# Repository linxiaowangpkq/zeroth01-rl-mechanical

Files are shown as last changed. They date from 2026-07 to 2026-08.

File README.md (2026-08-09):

# Zeroth-01 v5 original 16-DoF physical/RL baseline

v5 restores the released Zeroth-01 16-joint topology and proportions. It adds no ankle-roll motors, shortened shins, claws or large palms. The bounded changes are a rounded head enlarged by 5 mm on every side, a removable M5Stack UnitV2 camera/microphone, a direct no-neck head mount, two compact fixed wrist supports, two 9 mm white lower-wider replaceable soles, and explicit FEETECH STS3250 housing/output interfaces.

## Clone with CAD payloads

The STEP/GLB binaries are stored with Git LFS. A GitHub branch ZIP contains only
small LFS pointer text files and is **not** a complete offline CAD/RL delivery.
Use a Git clone and materialize the payloads before running any checksum gate:

```bash
git lfs install
git clone --branch codex/zeroth01-v5-16dof-solidworks-motion https://github.com/linxiaowangpkq/zeroth01-rl-mechanical.git
cd zeroth01-rl-mechanical
git lfs pull
python cad/physical_mount_v5_original_16dof_solidworks_motion/verify_v5_delivery_manifest.py
```

The verifier reports `git_lfs_pointer_not_materialized` with this remediation
when a required binary has not been downloaded.

## Authoritative RL files

- URDF: `generated/urdf/physical_mount_v5_original_16dof_solidworks_motion/zeroth01_physical_mount_v5_original_16dof_solidworks_motion.urdf`
- MJCF/MJX: `generated/mujoco/physical_mount_v5_original_16dof_solidworks_motion/zeroth01_physical_mount_v5_original_16dof_solidworks_motion_mjx.xml`
- RL model contract: `cad/physical_mount_v5_original_16dof_solidworks_motion/RL_MODEL_CONTRACT.md`
- Actuator layout: `generated/config/physical_mount_v5_original_16dof_solidworks_motion_actuator_layout.json`
- Hardware calibration template: `generated/config/physical_mount_v5_original_16dof_solidworks_motion_hardware_calibration.csv`
- RL handoff: `generated/config/physical_mount_v5_original_16dof_solidworks_motion_rl_handoff.json`
- SHA-256 delivery ledger: `generated/config/physical_mount_v5_original_16dof_solidworks_motion_delivery_manifest.json`
- Release truth boundary: `reports/v5_original_16dof_solidworks_motion/release_gate.json`
- 85-component CAD manifest: `generated/cad/physical_mount_v5_original_16dof_solidworks_motion/ZEROTH01_V5_ORIGINAL_16DOF_SOLIDWORKS_MOTION_ASSEMBLY_MANIFEST.json`
- 85-component coloured neutral review GLB: `generated/cad/physical_mount_v5_original_16dof_solidworks_motion/ZEROTH01_V5_ORIGINAL_16DOF_NEUTRAL_REVIEW.glb`
- 17 rigid-link STEP files: `generated/cad/physical_mount_v5_original_16dof_solidworks_motion/motion_link_parts/`

Current digital evidence: 16 revolute joints and 16 purchased-exact STS3250 STEP occurrences; 85 components; 17 positive-volume valid B-Rep motion links; zero positive interference among all 3,570 neutral-pose component pairs; 490.489 mm CAD envelope height; 416.448 mm MJCF standing kinematic height; 2.745759 kg nominal URDF/MJCF mass; and MuJoCo 3.3.7 compile at `nq=23`, `nv=22`, `nu=16`. For locomotion, reset from `gait_neutral`; `official_standing` is retained as the released calibration/standing-checkpoint pose.

The hip-yaw case path is physical CAD rather than a floating marker: two integrated torso ribs/bosses per side accept two M2x8 rear-case screws, while a PCD14 four-hole bridge and four M3 sleeves drive the U-hip. The mount and screw stack is clear of each moving U-hip over its unchanged full joint limit.

Native SOLIDWORKS static rebuild and 32 isolated lower/upper-limit Motion runs for the current manifest remain **HOLD** because the existing SOLIDWORKS process is unresponsive. Old native gate files are stale and are not acceptance evidence; no Motion GIF is claimed until the current assembly produces real frames.

This is a digital RL release, not a physical manufacturing sign-off. Purchased-part fit, printed strength, screw/tool access, exact internal electronics, harness flex, bus IDs/zeros/directions, as-built link mass/COM/inertia, current, thermal behavior and policy traces require first-article measurement and SysID.

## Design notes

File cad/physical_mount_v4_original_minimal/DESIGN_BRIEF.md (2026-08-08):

# Zeroth-01 v4 connected design brief

## Frozen baseline

- Preserve the released Zeroth-01 load-bearing torso, shoulder/hip spacing, upper limbs, thighs, source feet and all neutral joint axes.
- ToddlerBot, KHR-3HV, TonyPi and Open Duck Mini inform serviceability, double support, cable routing and MJX/SysID workflow only; their geometry is not substituted.
- The v3 RL frame/axis corrections remain frozen.

## Released changes

1. Two-piece rounded head, nominally +5 mm left/right/top/bottom, source depth retained, hidden 0.8 mm shoulder clearances, no visible neck.
2. Removable M5Stack UnitV2 camera/microphone cradle and direct four-M3 torso nut plate.
3. Original lightweight wrist termination only: no square palm, claw, gripper, ball hand or heavy Q-hand.
4. No external rear service pod or backplate. Compute, battery and IMU packaging must be frozen inside the torso after exact components are selected.
5. No added black sole; source feet define the contact surface.
6. Eighteen purchased-exact STS3250 occurrences. Every output has a 2.05 mm PCD14 bridge; required child-side standoffs close the torque path.
7. Hip-yaw servos move 4 mm only along their unchanged axes to clear the source torso. Four M2 case screws and four M3 PCD14 output tie rods close each joint; no fictitious solid spacer is installed.
8. Mirrored direct-drive ankle-roll carriers retain the original foot path; lower-leg straight spans are shortened 18 mm without altering terminal interfaces.

## Blocking gates

- 18/18 exact actuators and complete case/output torque paths.
- Bilateral axis/placement symmetry.
- 75/75 native SolidWorks occurrences and portable dependencies.
- Zero unapproved B-Rep cross-component interference. Threaded fastener engagement is allowed only for the explicitly paired PCD14 M3 shanks and only below 1.25 mm³ per detected engagement.
- Height ≤500 mm; nominal mass ≤3 kg.
- URDF/MJCF compile and 64-pose primitive collision sweep passes.
- Physical walking/running remains HOLD until first-article fit, printed strength, internal electronics/harness packaging, measured mass/SysID, current, thermal and policy traces are complete.

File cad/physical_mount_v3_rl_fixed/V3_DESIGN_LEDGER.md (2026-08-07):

# Zeroth-01 Physical Mount v3.1 Compact RL-Fixed Design Ledger

## Robot metadata

- Robot: `zeroth01_physical_mount_v3_rl_fixed_18dof`.
- Baseline: released v2-minimal appearance and source-carrier geometry.
- Consumers: MuJoCo/MJX RL, URDF viewers, SolidWorks/CAD review, first-article print review.
- Units: URDF/MJCF use m, kg, s, rad; CAD uses mm.
- Body convention: right-handed, `+X` forward, `+Y` left, `+Z` up.
- Mesh source: v2-minimal STL files are millimetre meshes and therefore use URDF scale `0.001`.

## Why v3 is 18DoF

The v2 topology has shoulder-yaw, shoulder-pitch and elbow-yaw on each arm,
plus hip-yaw, hip-roll, hip-pitch, knee-pitch and ankle-pitch on each leg.
It cannot independently regulate sole roll and torso roll in single support.
v3 adds one ankle-roll joint and STS3250 package per side.  Retaining 16DoF
would leave BUG-009 unresolved and therefore cannot be called an all-issues fix.

## Kinematic frames and positive motion

All movable child frames are located on their physical shaft centre and are
world-axis aligned in the neutral pose.  This removes the old mesh-frame RPY
coupling that mislabeled hip yaw/roll axes.  Visual transforms preserve the
v2 neutral appearance; collision and inertial frames are authored independently.

| Joint family | Left neutral axis | Right neutral axis | Positive motion |
|---|---:|---:|---|
| shoulder yaw | `+Z` | `-Z` | arm moves forward under mirrored controls |
| shoulder pitch | `+Y` | `+Y` | arm pitches forward |
| elbow yaw (historical name) | `+X` | `-X` | forearm hinges under mirrored controls |
| hip yaw | `+Z` | `-Z` | toe direction yaws outward under mirrored controls |
| hip roll | `+X` | `-X` | pelvis shifts toward the named support side |
| hip pitch | `+Y` | `+Y` | thigh moves forward (`+X`) |
| knee pitch | `+Y` | `+Y` | knee flexes backward |
| ankle pitch | `+Y` | `+Y` | toe pitches upward |
| ankle roll | `+X` | `-X` | sole medial edge rises under mirrored controls |

Left/right joint anchors are generated from one averaged source datum and an
explicit reflection across `Y=0`.  The release tolerance is 0.25 mm, tighter
than the failed v2 0.75 mm gate.

## Standing envelope, mass and inertia ledger

- Pre-compaction v3 nominal mass: `3.095471828 kg`.
- v3.1 nominal RL mass target: exactly `2.969171828 kg`, below the hard
  `3.000 kg` ceiling by `30.828 g` before as-built identification.
- Native SolidWorks standing-height hard gate: `<=500.0 mm`.  The previous
  STEP measured `572.678 mm`; the compact model sinks the head into the upper
  torso, re-clocks only the two new ankle-roll servos so their 45.22 mm case
  axis is horizontal, and uses a verified `30 mm` ankle-roll centre spacing.
- Final native SolidWorks occurrence-box height is `499.236652 mm` (`PASS`);
  the independent diagnostic STEP height is `494.818 mm`.  The SolidWorks
  value is the conservative release gate, while the built robot must still be
  measured because the remaining nominal margin is only `0.763 mm`.
- STS3250-C001 model mass: `0.0745 kg` each, 18 units, total `1.341 kg`.
- Remaining nominal mass covers source carriers, fasteners, lightened v2
  appearance parts, battery, compute, the purchased interaction head and IMUs.
- The former K151 head and large plate are deleted.  Their replacement is one
  purchasable M5Stack CoreS3 K128 main unit at the official
  `54.0 x 54.0 x 15.5 mm` envelope.  The official `72.7 g` whole-set weight is
  conservatively assigned to the main unit even though the DinBase is omitted,
  plus a `6 g` allowance for the hidden 2 mm 6061 U-cradle.
- Actuator mass is owned exactly once: each of the 18 actuated child links owns
  one 74.5 g STS3250 contribution, so no link is lighter than its contained servo.
- Every link inertia is calculated from its primitive collision envelope and
  nominal link mass.  Confidence is `estimated_from_envelope`, not measured.
- `MASS_IDENTIFIED_PASS` remains false until the assembled links are weighed
  and their centres of mass are measured.  RL may use the nominal model with
  the published randomisation range, but it must not be called as-built truth.

## Collision ledger

- RL collision geometry is primitive-only: boxes, spheres, cylinders and capsules.
- Limb capsules are generated from the true joint-to-child vector rather than a
  hard-coded vertical box, so collision geometry follows the actual kinematic chain.
- The torso collision proxy is the central structural spine and deliberately
  excludes the shoulder cut-outs used by the two shoulder chains.
- Each sole has its own symmetric box collision and four contact frames.
- Detailed v2 visual meshes never participate in MJX contact.
- The printable 7 mm sole is lightened with a 2 mm skin and 5 mm perimeter/rib
  stack; its collision envelope remains a closed 7 mm box.

## STS3250 interface ledger

- Controlled dimensions: case `45.22 x 24.72 x 35.0 mm`, shaft centre 12.5 mm
  from the short end, 25T/5.9 mm output, M3x6 retention.
- Drawing-derived case holes: 4-M2.0, centres `X={-28.50, 8.30} mm`,
  `Y={-10.25, 10.25} mm` in the controlled shaft frame.
- The step.parts record `feetech_sts3250` is checksum-verified but its embedded
  STEP product is `ST-3235M-20211119-A_ASM`; it remains quarantined and is not
  treated as an exact C001 installation B-Rep.
- v3 uses the dimension-controlled STEP and the existing source carrier
  datums.  Full-print release remains blocked until one purchased STS3250
  passes the 4-M2/25T/rear-support first-article gauge.

## Full assembly ownership

- The native/full CAD handoff is driven by the external-part assembly manifest,
  not by a fused display solid.  It contains 51 independently addressable
  components: retained v2 carriers and white shells, 18 blue STS3250 instances,
  two ankle-roll carrier/horn sets, two 7 mm soles, CoreS3 and its hidden cradle.
- Servo instance IDs `S01`--`S18`, shaft frames and source part paths are recorded
  in the manifest and actuator-layout JSON so SolidWorks and RL use one datum set.
- Legacy claw parts, the legacy 16 placeholder servo bodies and all nine custom
  head/display/camera parts are excluded.

## Purchased interaction head

- Selected module: M5Stack CoreS3 K128, official main-unit envelope
  `54.0 x 54.0 x 15.5 mm`; conservative assigned mass `72.7 g`.
- Integrated functions: 2-inch 320x240 capacitive IPS display, GC0308 0.3 MP
  camera, dual microphones, 1 W speaker, proximity/ambient sensor, BMI270
  6-axis IMU, BMM150 magnetometer, Wi-Fi and internal 500 mAh battery.
- The module is fixed during walking and introduces no moving head axes.  Its
  height spans `z=-9..45 mm` and is flush-sunk into the body installation
  pocket, so it creates neither a neck nor any extra standing height.
- A hidden 2 mm 6061 U-cradle touches the rear and three perimeter faces of the
  controlled module envelope.  The body contains the matching recessed slot,
  four M3 passages and `0.20 mm` cradle clearance.  Fit remains a first-article
  item because the official repository provides an STL rather than a tolerance
  drawing for this robot-specific interface.
- The body also contains `0.30 mm` case clearance around both hip-yaw servos.
  SolidWorks reports `0` cross-component physical interferences.  Its five
  remaining same-component rows are intentional union overlaps between bodies
  inside the one legacy carrier SLDPRT, not collisions between installed parts.
- Official source: `https://docs.m5stack.com/en/core/CoreS3` and the K128
  structure repository.  The generated STEP is a controlled purchased envelope,
  not an instruction to print a substitute controller.

## Independent release gates

1. `CAD_PORTABLE_PASS`: generated STEP/STL/SolidWorks files open and resolve.
2. `KINEMATIC_SYMMETRY_PASS`: paired joint anchors/axes satisfy the v3 mirror rule.
3. `MJX_PRIMITIVE_COLLISION_PASS`: no mesh collision enters the RL model.
4. `GROUND_CONTACT_PASS`: official standing keyframe has two level soles at ground.
5. `ACTUATOR_STATIC_FEASIBILITY_PASS`: nominal whole-body static check is below
   the rated limit, but the detailed quasistatic sweep peaks at `1.414238 N.m`
   on left ankle pitch, above the `1.255251 N.m` continuous design limit and
   below the `1.569064 N.m` rated limit; dynamic walking therefore remains HOLD
   until constrained RL torque/current/thermal traces pass.
6. `MASS_TARGET_PASS`: nominal mass is positive, `<=3.0 kg`, and equals the locked target.
7. `STANDING_HEIGHT_LIMIT_PASS`: native SolidWorks occurrence union is `<=500 mm`.
8. `MASS_IDENTIFIED_PASS`: only after as-built measurements; expected `HOLD` now.
9. `STS3250_FIRST_ARTICLE_PASS`: only after purchased-hardware fit; expected `HOLD` now.

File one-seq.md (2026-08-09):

克隆 https://github.com/linxiaowangpkq/zeroth01-rl-mechanical.git 的 `codex/zeroth01-v5-16dof-solidworks-motion` 分支并执行 `git lfs pull`，先读 `README_zh.md`、`bug.md`、`cad/physical_mount_v5_original_16dof_solidworks_motion/RL_MODEL_CONTRACT.md`、`reports/v5_original_16dof_solidworks_motion/release_gate.json` 和 RL handoff，只用新 canonical v5 原始 16DoF MJCF 的 `gait_neutral` 复位及其 16 维 `ctrl/qpos/joint` 映射，按 ToddlerBot 式 MJX→SysID→域随机化流程重新训练站立/步行/跑步并在每个 checkpoint 记录源 commit、MJCF SHA-256、控制顺序以及峰值/RMS 扭矩、电流/温升估计、足底接触、跌倒和碰撞统计，禁止把旧 N12 站立策略称为步行、禁止臆造总线 ID、实体零位/方向、实测惯量、原生 SOLIDWORKS Motion 或实物首件 PASS。

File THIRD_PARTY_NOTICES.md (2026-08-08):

# Third-party notices

The top-level MIT License covers original scripts, validation logic,
documentation and newly generated reference/gauge geometry. It does not
replace third-party licenses or vendor rights.

## Zeroth / K-Scale Z-Bot source

- Repository: <https://github.com/kscalelabs/kscale-assets>
- Pinned commit: `f51d6ea19b8b824dd7661600c7a87f3691f770be`
- Source path: `zbot/`
- Local release path: `upstream/kscale-assets/zbot/`
- Repository status: archived/read-only.

The 16 installed servo regions and 20 carrier meshes are derived from those
pinned triangulated assets. The source did not include native SolidWorks or
STEP B-Rep parts; this release does not claim otherwise.

Related MIT notices retained in `LICENSES/`:

- `ZEROTH_SIM_MIT.txt`
- `ZEROTH_BOT_MIT.txt`
- `KSCALE_ONSHAPE_MIT.txt`

Machine-readable provenance is in
`source_assets/PHYSICAL_MOUNT_V1_SOURCE_LOCK.json`.

## FEETECH

STS3215 and STS3250 specifications/drawings remain copyright of FEETECH. They
are redistributed only as engineering references; FEETECH names and marks
belong to their owner.

- STS3250 official specification:
  <https://www.feetechrc.com/Data/feetechrc/upload/file/20240120/6384135881578380868917773.pdf>
- STS3215 official specification:
  <https://www.feetechrc.com/Data/feetechrc/upload/file/20200611/6372749961523760249976542.pdf>

V4 uses 18 independent occurrences normalized from the downloadable STS3250
CAD hosted by step.parts:

- Catalog page: <https://www.step.parts/parts/feetech_sts3250>
- Preserved download: `source_assets/step_parts/feetech_sts3250.step`
- SHA-256: `cf46f17da455e1f158114791bb31404c24d925e8a758bbd6189f8ee815a571bf`

This is substantially more detailed than the former drawing-derived box, but
it is still third-party reference CAD and not a substitute for checking the
purchased actuator, threads, spline, cable exit and production tolerances.

## Engineering workflow references

V4 does not redistribute or copy geometry from the following projects. Their
public documentation informed service splitting, double-supported brackets,
cable routing, MJX/SysID and training workflow only; their own licenses and
trademarks remain with their authors.

- ToddlerBot: <https://github.com/hshi74/toddlerbot>
- Open Duck Mini: <https://github.com/apirrone/Open_Duck_Mini>
- KHR-3HV documentation: <https://kondo-robot.com/faq/khr-3hv-erection-diagram>
- TonyPi documentation: <https://docs.hiwonder.com/projects/TonyPi/en/latest/>

M5Stack UnitV2 dimensions, camera and microphone descriptions are vendor
facts. The v4 envelope and cradle are newly modelled references, not vendor
CAD: <https://docs.m5stack.com/en/unit/unitv2>.

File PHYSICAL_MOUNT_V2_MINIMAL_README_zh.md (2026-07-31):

# Zeroth-01 Physical Mount V2 Minimal（RL 机械基线）

本版本以已经通过干涉检查的 Physical Mount V1 为机械主链，只做最小、可逆改动：替换头部、增加浅圆角胸板、删除旧爪并替换为小型 Q 手、增加 9 mm 可更换脚底。**16 个关节、安装骨架、关节轴与舵机归属均未重排。**

## 当前结论

| 项目 | 结果 | 证据 |
|---|---:|---|
| 外挂脖子 | **无独立脖子组件** | SolidWorks `external_neck_component_count=0` |
| 原骨架头柱最大外露 | **1.404 mm** | 自动门限 ≤5 mm，PASS |
| 头/胸装配缝 | 0.60 mm、无相交 | STEP 实体布尔门，PASS |
| 胸板前后深度 | 8.775 mm | 浅圆角面板，不再是厚方盒 |
| SolidWorks 装配 | 51/51 组件 | 20 承力件 + 16 独立蓝色舵机 + 15 外观/电子件组件 |
| 旧爪 | 0 | 两个原前臂固定爪已切除，FINGER link 改为 Q 手 |
| Q 手外包络 | 45.0 × 40.55 × 38.0 mm | 左右镜像，双耳 M3 横穿安装 |
| 脚底 | 9 mm | 左右可更换接触底，TPU/PETG 首件 |
| URDF | 16 个 revolute joint | 总标称质量 5.216675 kg，逐 link 质量/质心/惯量齐全 |
| MuJoCo | PASS | 中位、16×61 单关节采样、73 个协同姿态均无非相邻刚体碰撞 |
| 整机直接打印 | **HOLD** | 先做一颗 STS3250 量规和一套头/腕/脚底首件 |

## 唯一推荐入口

- RL URDF：`generated/urdf/physical_mount_v2_minimal/zeroth01_physical_mount_v2_minimal.urdf`
- RL 总交接：`generated/config/physical_mount_v2_minimal_rl_handoff.json`
- 16 舵机数据：`generated/config/physical_mount_v1_actuators.json`
- 舵机标定模板：`generated/config/physical_mount_v1_hardware_calibration_template.csv`
- 打印件质量/质心/惯量：`generated/config/physical_mount_v2_minimal_mass_properties.json`
- SolidWorks 便携透视装配：`generated/solidworks/physical_mount_v2_minimal/portable_flat/OPEN_FIRST_ZEROTH01_PHYSICAL_MOUNT_V2_MINIMAL_16_BLUE_SERVOS_XRAY.SLDASM`
- SolidWorks 便携正常外观：`generated/solidworks/physical_mount_v2_minimal/portable_flat/ZEROTH01_PHYSICAL_MOUNT_V2_MINIMAL_WHITE_NORMAL.SLDASM`
- STEP/STL：`generated/cad/physical_mount_v2_minimal/parts/`
- 一键发布校验：`python scripts/validate_minimal_v2_release.py`

Physical Mount V1 被保留为来源机制和 STS3250 首件接口依据，但不再是推荐训练入口。

## 坐标、电子件与传感器位置

URDF 使用米/千克/弧度；机器人左侧为 `+X`、前方为 `-Y`、上方为 `+Z`。以下均相对 `Z_BOT2_MASTER_BODY_SKELETON`：

| 部件 | SolidWorks 颜色 | 中心 XYZ (m) | 标称质量 | 状态 |
|---|---|---:|---:|---|
| Waveshare 4.3" DSI QLED 显示 | 青色 | `[0, -0.043, 0.070]` | 0.129 kg | 已选产品，夹具需打印试配 |
| Raspberry Pi Camera Module 3 Wide | 绿色 | `[0, -0.033, 0.105]` | 0.004 kg | 产品尺寸/STEP 依据 |
| VL53L5CX ToF 载板包络 | 紫色 | `[0.029, -0.038, 0.108]` | 0.002 kg | 传感器已选，载板待冻结 |
| SBC/载板/稳压器包络 | 橙色 | `[0, 0.042, -0.002]` | 0.180 kg | RL 假设，型号待冻结 |
| 3S2P 电池+BMS 包络 | 品红 | `[0, 0.028, -0.052]` | 0.340 kg | RL 假设，电芯/BMS 待冻结 |
| 躯干 IMU | 亮绿 | `[0, 0.012, 0.018]` | 0.012 kg | RL 假设，型号/方向待冻结 |

相机与 ToF 的 REP-103 光学坐标、四个脚底接触 frame 已写进 URDF 和 handoff JSON。正常 SolidWorks 装配隐藏内部电子件；透视装配显示全部不同颜色包络。

## 16 个蓝色舵机究竟是什么

SolidWorks 中的 `S01`–`S16` 是从原 Zeroth 装配中按原刚体归属提取的 **STS3215-family 安装实体**，不是随意摆放的蓝色盒子：

- 每颗舵机是独立 `.SLDPRT`；
- 每颗跟随其真实 owning link 和 16DoF 正向运动学；
- 左右看似不完全同向来自镜像机构和关节坐标，不允许为了画面对称而旋转；
- 装配树名称同时包含 `Sxx` 与关节名，可在 SolidWorks 中单独隐藏、剖视或测量。
- 发布仓库采用 SolidWorks Pack and Go 生成的 `portable_flat` 同目录包；两套 `.SLDASM` 与 51 个 `.SLDPRT` 放在同一目录，克隆后不依赖原开发机绝对路径。

目标执行器仍是 FEETECH `STS3250-C001`：12 V、74.5 g、额定持续扭矩 1.569 N·m、堵转扭矩 4.903 N·m、URDF 速度上限 3.0 rad/s。训练不得把堵转扭矩当持续输出。

STS3250 和源 STS3215-family 的名义壳体家族接近，但官方 STS3250 的 4×M2、25T 舵盘、后轴与实物公差尚未完成首件签核，所以蓝色件必须理解为“安装位置真值”，不是供应商精确 B-Rep。首件量规仍位于：

- `generated/cad/physical_mount_v1/sts3250_interface/FEETECH_STS3250_C001_DIMENSION_REFERENCE.step`
- `generated/cad/physical_mount_v1/sts3250_interface/STS3250_4XM2_FIRST_ARTICLE_FACE_GAUGE.step`
- `generated/print/physical_mount_v1/first_article/STS3250_4XM2_FIRST_ARTICLE_FACE_GAUGE.stl`

## 3D 打印和装配边界

17 组 v2 STEP/STL 均通过拓扑检查；其中头前壳、头后壳、胸板、相机支架、左右 Q 手和左右脚底为打印件。显示器、相机、ToF、计算板、电池、IMU 与 UI/window 几何是受控安装包络，不应直接当成打印件。

推荐顺序：

1. 打印 STS3250 4×M2 首件量规，只拿一颗实物验证孔、舵盘和后轴；
2. 打印一套头前/后壳、相机支架，实装显示器/相机/ToF 并检查 FFC/CSI 出线；
3. 打印一只 Q 手和一块脚底，验证双耳 M3、腕部间隙、落地面与紧固件；
4. 通过后才打印左右成套件；
5. 装 16 颗舵机时逐颗做总线扫描、方向点动和机械零位，填写 calibration CSV；
6. 走完整受限关节运动，确认线束弯曲半径，再称量各总成并更新 URDF 惯量。

因此结论不是“现在整机直接打印即可拼装”，而是“CAD/URDF 已可训练和做分件首件，整机打印仍由 STS3250 与头/腕/脚首件门控制”。

## 仿真证据与边界

- `reports/physical_mount_v2_minimal/geometry_gate.json`：头柱外露 1.404 mm、0.60 mm 头胸缝、Q 手与脚底尺寸、STEP/STL 拓扑；
- `reports/physical_mount_v2_minimal/dynamic_collision_gate.json`：MuJoCo 3.11.0 中位、单关节和协同动作；
- `reports/physical_mount_v2_minimal/solidworks_gate.json`：51 组件、16 舵机、0 旧爪、0 外挂脖子、视图和 GIF；
- `reports/physical_mount_v2_minimal/release_gate.json`：可移植 URDF、质量惯量、CAD 数量和交付完整性总门。

SolidWorks GIF 是 CLI 正向运动学驱动原生组件 transform 的证据；碰撞结论来自同一 URDF/几何的 MuJoCo 采样门。它不是 SolidWorks Motion 的连续接触求解，也不证明全 16 维关节极限笛卡尔积无自碰撞。RL 必须保留自碰撞惩罚/终止。

## RL 使用方式

先运行：

```bash
python scripts/validate_minimal_v2_release.py
```

然后以 v2-minimal URDF 为唯一机械真值，读取 handoff 中的关节、逐 link 惯量、传感器 frame、接触点、额定扭矩和域随机化范围。当前可做刚体 PPO 步行与 STS3250 额定扭矩可行性研究；sim-to-real 仍需实际总线/方向/零位、首件装配、线束、整机质量/质心/惯量、相机/ToF/IMU 标定和热/电压裕量。

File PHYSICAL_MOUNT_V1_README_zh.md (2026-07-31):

# Zeroth-01 Physical Mount V1

这是替代旧版“蓝色舵机包络叠加图”的机械基线。旧图只适合标位置，不能证明舵机可安装、可传动或左右对称；本版直接从 Zeroth/K-Scale 已装配的原始 STL 中拆出 16 个舵机实体，并保留它们在承力件中的原坐标、原关节轴和父子链。

## 当前结论

| 项目 | 结果 | 含义 |
|---|---:|---|
| 原装配舵机实体提取 | PASS，16/16 | 每个蓝色件都来自原始装配网格，不是重新摆放的长方体 |
| 舵机壳体—输出轴偏置 | PASS，16/16 | 实测约 12.5 mm，与 FEETECH STS32xx 图纸一致 |
| 肩、肘严格左右镜像 | PASS | 轴线/壳体镜像误差约 0.02–0.16 mm |
| 髋 yaw/roll 传动轴镜像 | PASS | hip-roll 两侧沿输出轴的壳体方向不同，不影响轴线重合 |
| hip-pitch、膝、踝严格镜像 | REVIEW | 原始源模型自带约 1.45–1.48 mm 横向偏差；未擅自移动舵机掩盖问题 |
| MuJoCo 非相邻件干涉 | PASS | 中位姿 0；每关节 61 点全程 0；73 个协调动作姿态 0 |
| SolidWorks 分件装配 | PASS | 36 个分件、20 个刚性子装配、16 个蓝色舵机件 |
| STS3250 首件量规 CAD | PASS | STEP/STL 均为闭合有效几何 |
| 整机直接打印 | **HOLD** | 必须先拿一颗实物 STS3250 验证 4×M2、25T 舵盘和后轴支撑 |

因此，答案不是“已经可以无条件打印整机”，而是：

- 旧图确实不能证明安装与传动，现已废止。
- 本版证明了原 Zeroth-01 的 STS3215-family 安装实体、承力件与关节轴属于同一条真实装配链。
- STS3250 与该家族的名义外形和轴系接近，但完整螺孔公差尚未由实物签核，所以整机打印仍保持 HOLD。

## 为什么旧图看起来左右不对称

旧版把 16 个蓝色包络按父坐标系放在白色模型外面，仅用于“编号可见性”。它没有使用原网格中已经存在的舵机区域，也没有把包络固定到对应承力件，因此肩、髋、肘会出现漂浮、交叉和左右姿态不一致。

原 Zeroth-01 STL 又把舵机、法兰、舵盘和承力件合并成同色三角网格，所以普通显示下看不到独立舵机。Physical Mount V1 按连通区域拆分后：

- 白色：原承力件、法兰、舵盘/连接结构；
- 蓝色：原装配内嵌的 STS3215-family 舵机实体；
- 每个蓝色件与所属 link 保持单位变换，不再人为平移或旋转；
- 关节运动仍使用原 URDF 的 parent、child、origin 和 axis。

透视图：

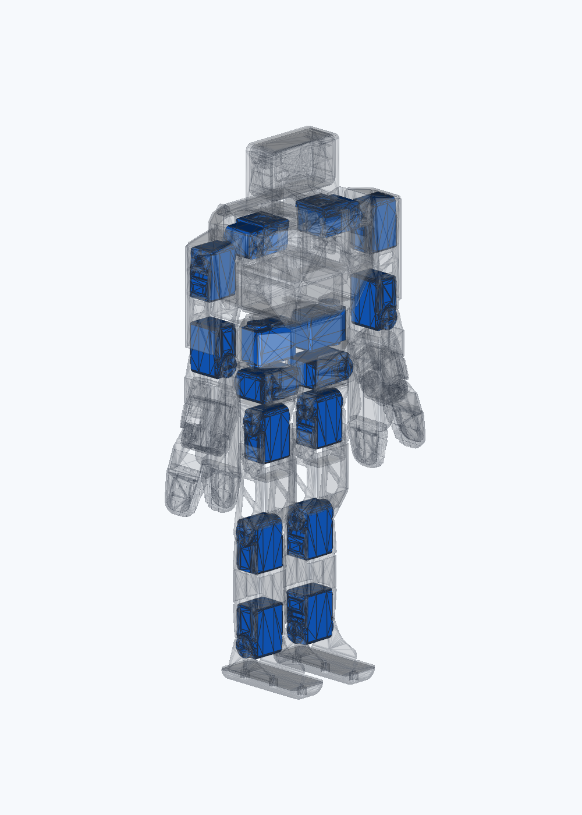
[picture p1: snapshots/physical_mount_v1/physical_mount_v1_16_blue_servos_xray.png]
16 个原位舵机透视图


协调动作：

16DoF 协调动作

## 16 个舵机与承力件

| ID | 关节 | 舵机实体所在承力 link | 相对关节 |
|---|---|---|---|
| S01 | right_shoulder_pitch | 3215_1Flange_2 | child |
| S02 | left_shoulder_pitch | 3215_1Flange | child |
| S03 | right_shoulder_yaw | Z_BOT2_MASTER_BODY_SKELETON | parent |
| S04 | right_hip_pitch | 3215_BothFlange_10 | child |
| S05 | left_hip_pitch | 3215_BothFlange_9 | child |
| S06 | left_shoulder_yaw | Z_BOT2_MASTER_BODY_SKELETON | parent |
| S07 | right_hip_yaw | Z_BOT2_MASTER_BODY_SKELETON | parent |
| S08 | left_hip_yaw | Z_BOT2_MASTER_BODY_SKELETON | parent |
| S09 | right_elbow_yaw | 3215_1Flange_2 | parent |
| S10 | left_elbow_yaw | 3215_1Flange | parent |
| S11 | right_hip_roll | 3215_BothFlange_6 | child |
| S12 | left_hip_roll | 3215_BothFlange_5 | child |
| S13 | right_knee_pitch | 3215_BothFlange_14 | child |
| S14 | left_knee_pitch | 3215_BothFlange_13 | child |
| S15 | right_ankle_pitch | 3215_BothFlange_14 | parent |
| S16 | left_ankle_pitch | 3215_BothFlange_13 | parent |

完整坐标、源 region、SHA256、轴距与镜像误差分别在：

- `reports/physical_mount_v1/servo_component_manifest.csv`
- `reports/physical_mount_v1/kinematic_mount_audit.csv`
- `config/physical_mount_v1_source_regions.json`

## STS3250 边界

FEETECH 官方 STS3250 图纸给出：

- 壳体名义尺寸 45.22 × 24.72 × 35 mm；
- 双输出总深度 36.5 mm；
- 输出轴距短端 12.5 mm；
- 25T、外径约 5.9 mm；
- 输出固定螺钉 M3×6；
- 壳体安装 4×M2；
- 质量 74.5±1 g；
- 12 V 额定扭矩 16 kg·cm，堵转扭矩 50 kg·cm。

官方资料：

- STS3250：<https://www.feetechrc.com/Data/feetechrc/upload/file/20240120/6384135881578380868917773.pdf>
- STS3215：<https://www.feetechrc.com/Data/feetechrc/upload/file/20200611/6372749961523760249976542.pdf>

蓝色 SolidWorks 零件被明确命名为 `INSTALLED_STS3215_FAMILY_REFERENCE`，因为它们来自原 Zeroth 装配，而不是供应商发布的精确 STS3250 B-Rep。精确尺寸控制另有：

- `generated/cad/physical_mount_v1/sts3250_interface/FEETECH_STS3250_C001_DIMENSION_REFERENCE.step`
- `generated/cad/physical_mount_v1/sts3250_interface/STS3250_4XM2_FIRST_ARTICLE_FACE_GAUGE.step`
- `generated/print/physical_mount_v1/first_article/STS3250_4XM2_FIRST_ARTICLE_FACE_GAUGE.stl`

量规的 36.8 × 20.5 mm 孔距是依据图纸轮廓/边距重建的待验证值，不冒充供应商公差尺寸。

## SolidWorks

先打开：

`generated/solidworks/physical_mount_v1/OPEN_FIRST_ZEROTH01_PHYSICAL_MOUNT_V1_16_BLUE_SERVOS.SLDASM`

结构：

- `parts/skeleton/`：20 个白色承力 surface parts；
- `parts/servos/`：16 个蓝色原装配舵机 reference parts；
- `links/`：20 个固定 link 子装配，每个包含承力件和属于该 link 的舵机；
- 顶层装配：按 URDF 正运动学变换摆放 20 个 link 子装配；
- `ZEROTH01_PHYSICAL_MOUNT_V1_16_BLUE_SERVOS_XRAY.SLDASM`：透视复核版。

上游只发布 STL，SolidWorks 因此保存的是原尺寸 surface parts，不是带圆柱面配合、孔特征树和原生 Motion 接触的参数化 B-Rep。当前 GIF 证明的是 SolidWorks 装配变换可执行；几何干涉门由详细网格 MuJoCo 扫描独立完成。

## RL 入口

主 URDF：

`generated/urdf/physical_mount_v1/zeroth01_physical_mount_v1.urdf`

关键数据：

- 16 个 revolute joints，左右名称显式化；
- 两个 gripper 固定，因此不虚增执行器；
- 总质量 4.064411 kg；
- 每颗 STS3250 按 74.5 g 计入，原 55 g 舵机质量用每颗 +19.5 g 点质量修正；
- URDF effort 使用 12 V 额定扭矩 1.569 N·m，不用 4.903 N·m 堵转值训练持续动作；
- 每关节 guarded limits 已写入 URDF；
- 舵机总线 ID、方向符号、硬件零位均标为必须实机标定，不伪造；
- 1000 个全 16D 独立随机姿态中有 117 个自碰撞是诊断结果，RL 必须保留自碰撞惩罚/终止，不能把各关节独立极限的笛卡尔积当作全局安全域。

执行器与不确定性：

- `generated/config/physical_mount_v1_actuators.json`
- `generated/config/physical_mount_v1_hardware_calibration_template.csv`
- `generated/config/physical_mount_v1_rl_handoff.json`
- `config/physical_mount_v1_guarded_limits.json`

质量/惯量当前是“开源源模型 + STS3250 质量增量”的工程基线。电池、算力板、屏幕、线束和最终打印件必须在实物完成后称重、测质心并回写；在此之前 RL 应按 handoff JSON 的建议做质量、质心、摩擦和扭矩域随机化。

## 打印顺序

不要先打印整机：

1. 打印 4×M2 首件量规；
2. 用一颗实际购买的 STS3250 验证孔距、螺纹深度、35/36.5 mm 深度、25T 舵盘和后轴；
3. 只打印一个肩部模块和一个髋部模块，检查装入、锁紧、线束出口和全行程；
4. 把实测尺寸写入 `reports/physical_mount_v1/first_article_measurements.csv`；
5. 修正承力件并重新跑轴线、干涉和 SolidWorks gate；
6. 以上全部通过后才把整机打印状态从 HOLD 改为 RELEASED。

详见 `ASSEMBLY_GUIDE_zh.md`。

## 可审计门

- `reports/physical_mount_v1/source_component_gate.json`
- `reports/physical_mount_v1/kinematic_mount_audit.json`
- `reports/physical_mount_v1/dynamic_collision_gate.json`
- `reports/physical_mount_v1/solidworks_physical_mount_gate.json`
- `reports/physical_mount_v1/sts3250_interface_gauge.json`

这些门分别回答“来自哪里、轴是否对、是否干涉、SolidWorks 是否分件、能否进入实物首件”，不能互相替代。

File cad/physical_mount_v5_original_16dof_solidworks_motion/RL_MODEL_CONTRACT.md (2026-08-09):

# Zeroth-01 v5 16DoF RL model contract

This ledger freezes the assumptions shared by MuJoCo/MJX training, checkpoint
metadata and later hardware deployment. The generated source of truth is
`build_v5_mjcf.py`; `reports/v5_original_16dof_solidworks_motion/mjcf_compile_gate.json`
contains the machine-checked mapping and the SHA-256 of the resulting MJCF.

## Frames and units

- SI units: metres, kilograms, seconds, radians and newton-metres.
- World/body-neutral axes: +X forward, +Y left, +Z up.
- Floating-base `qpos[0:7]`: position XYZ followed by MuJoCo quaternion WXYZ.
- Floating-base `qvel[0:6]`: linear XYZ followed by angular XYZ velocity.
- The released CAD/URDF joint axes, limits, geometry, collision primitives,
  mass, COM, inertia and the 1.2552512 N m continuous training torque cap are
  unchanged by the RL contract repair.

## Canonical index order

The compiler's depth-first hinge order is authoritative:

```text
0  left_shoulder_yaw       qpos 7   qvel 6
1  left_shoulder_pitch     qpos 8   qvel 7
2  left_elbow_yaw          qpos 9   qvel 8
3  right_shoulder_yaw      qpos 10  qvel 9
4  right_shoulder_pitch    qpos 11  qvel 10
5  right_elbow_yaw         qpos 12  qvel 11
6  left_hip_yaw            qpos 13  qvel 12
7  left_hip_roll           qpos 14  qvel 13
8  left_hip_pitch          qpos 15  qvel 14
9  left_knee_pitch         qpos 16  qvel 15
10 left_ankle_pitch        qpos 17  qvel 16
11 right_hip_yaw           qpos 18  qvel 17
12 right_hip_roll          qpos 19  qvel 18
13 right_hip_pitch         qpos 20  qvel 19
14 right_knee_pitch        qpos 21  qvel 20
15 right_ankle_pitch       qpos 22  qvel 21
```

`ctrl[i]`, policy action `i` and the joint on row `i` above are identical.
Generation fails if actuator order, compiled order or qpos/qvel addresses
diverge. Checkpoints must record this order and the canonical MJCF SHA-256.

## Reset poses

- `official_standing` is the released all-zero calibration pose. It is retained
  for compatibility and standing-checkpoint replay, but four knee/ankle joints
  are on a one-sided model limit, so it is not the locomotion reset.
- `gait_neutral` is the required training reset. Its leg values are left
  `(+0.18, -0.36, -0.18)` and right `(-0.18, +0.36, +0.18)` for
  hip-pitch, knee-pitch and ankle-pitch. Its base Z is solved from both sole
  boxes. `symmetric_crouch` is an exact backward-compatible alias.
- Generation checks all values against limits, both sole bottoms against the
  ground, left/right world mirror error and at least 5 degrees of positive and
  negative knee/ankle travel.

## Foot sites and unresolved physical truth

Foot sites are named by world semantics: front sites have greater world X than
rear sites, and medial sites have smaller absolute world Y than lateral sites.
Both conditions are checked from `official_standing` forward kinematics.

The SolidWorks physical-zero audit and powered servo zero/direction calibration
remain HOLD. Therefore this repair does not reinterpret physical hard stops or
claim that an encoder count corresponds to `official_standing` or
`gait_neutral`; those mappings belong in the hardware calibration CSV after
first-article measurement.

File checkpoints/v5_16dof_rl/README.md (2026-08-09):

# Zeroth-01 v5 16DoF RL milestones

这里只保存通过明确仿真门禁的冻结 checkpoint。N/M/Z 分别表示站立、步行和跑步，不代表 PPO 更新总数或实体部署许可。

| 里程碑 | 文件 | 状态 |
|---|---|---|
| N12 `gait_neutral` 站立 | `N12_gait_neutral_standing/ckpt.12.bin` | PASS；canonical 中立姿态回归 |
| N12 历史零位站立 | `N12_standing/ckpt.12.bin` | PASS / 仅旧模型回归 |
| M4 步行 | `M4_robust_walk/ckpt.4.bin` | PASS；8/8 × 4 s，0.106928 m/s |
| Z4 跑步 | `Z4_robust_run/ckpt.4.bin` | PASS；8/8 × 4 s，0.150424 m/s，飞行相 0.03 |

全部新 checkpoint 是 46 维观测、16 维全身 PPO 动作，六个手臂关节和十个腿部关节均由策略输出；每个执行器扭矩限制为 `±1.2552512 N·m`。

Z4 是仿真跑步里程碑，不是 STS3250 实机合格证明。其 10 s 负载复放显示膝关节 p95 速度约 5.0 rad/s，高于配置中的 3 rad/s 包络。对 Z4 加硬 3 rad/s 目标速率后 0/8 生存且飞行相消失；硬约束 PPO v14 训练 147,201 样本后仍为 0/8。因此实体跑步必须先关闭 `bug.md` 中的 BUG-RL-V5-007。

详细门禁、恢复、随机策略对照和硬件负载证据见 `reports/rl_training/v5_16dof_20260809/`。没有执行任何实体舵机命令。

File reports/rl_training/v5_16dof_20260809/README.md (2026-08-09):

# 2026-08-09 16DoF RL evidence

本目录把可审计的训练/门禁摘要随机械基线保存；原始训练工程、视频、完整逐物理步 trace 和可恢复训练入口仍位于 RL 工作区。

- `Z4_gate_report.json`：正式 8 × 4 s 跑步门禁。
- `Z4_restore_report.json`：CUDA checkpoint 恢复和 46→16 shape 契约。
- `Z4_vs_random.json`：同种子随机策略对照。
- `M4_hardware_load_report.json` / `M4_joint_hardware_statistics.csv`：步行负载审计。
- `L3_hardware_load_report.json` / `L3_joint_hardware_statistics.csv` / `L3_foot_impact_slip_statistics.csv`：10 s 跑步负载审计。
- `L3_joint_torque_speed.png`：每关节扭矩-速度散点。
- `STS3250_reference_search_2000x4x10s.json`：2,000 个参考步态、4 种子、10 s 的速度/飞行搜索。
- `V13_soft_speed_constraint_screen.json`：软速度约束 PPO 全 checkpoint 外部复放。
- `Z4_hard_3rad_slew_screen.json`：原 Z4 在硬 3 rad/s 目标速率下的复放。
- `V14_hard_3rad_training_screen.json`：硬速率执行器 PPO 全 checkpoint 联合门禁。

电流、温升和母线压降使用报告中显式记录的假设；在真实 STS3250 系统辨识前，不得视为实测值或上机许可。

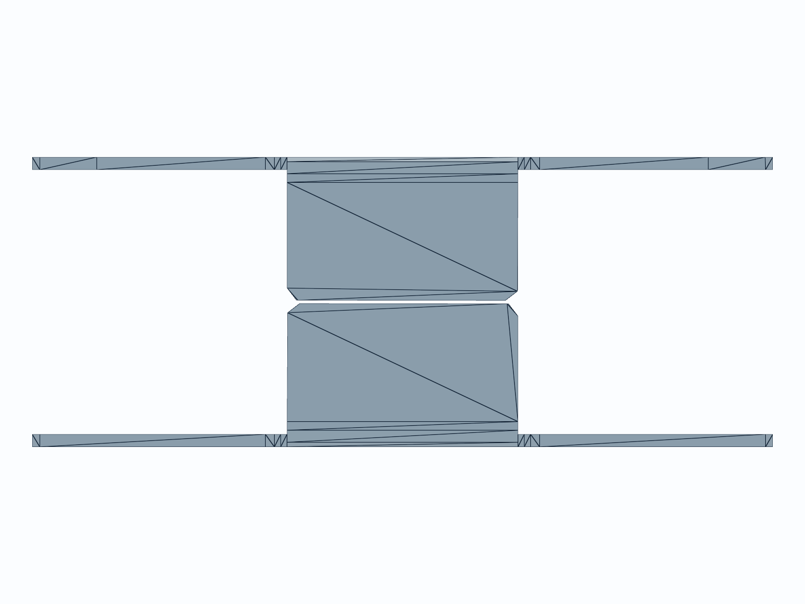
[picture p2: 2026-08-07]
reports/v4_original_minimal/audit/lower_leg_source_front_20260807T202301Z.png

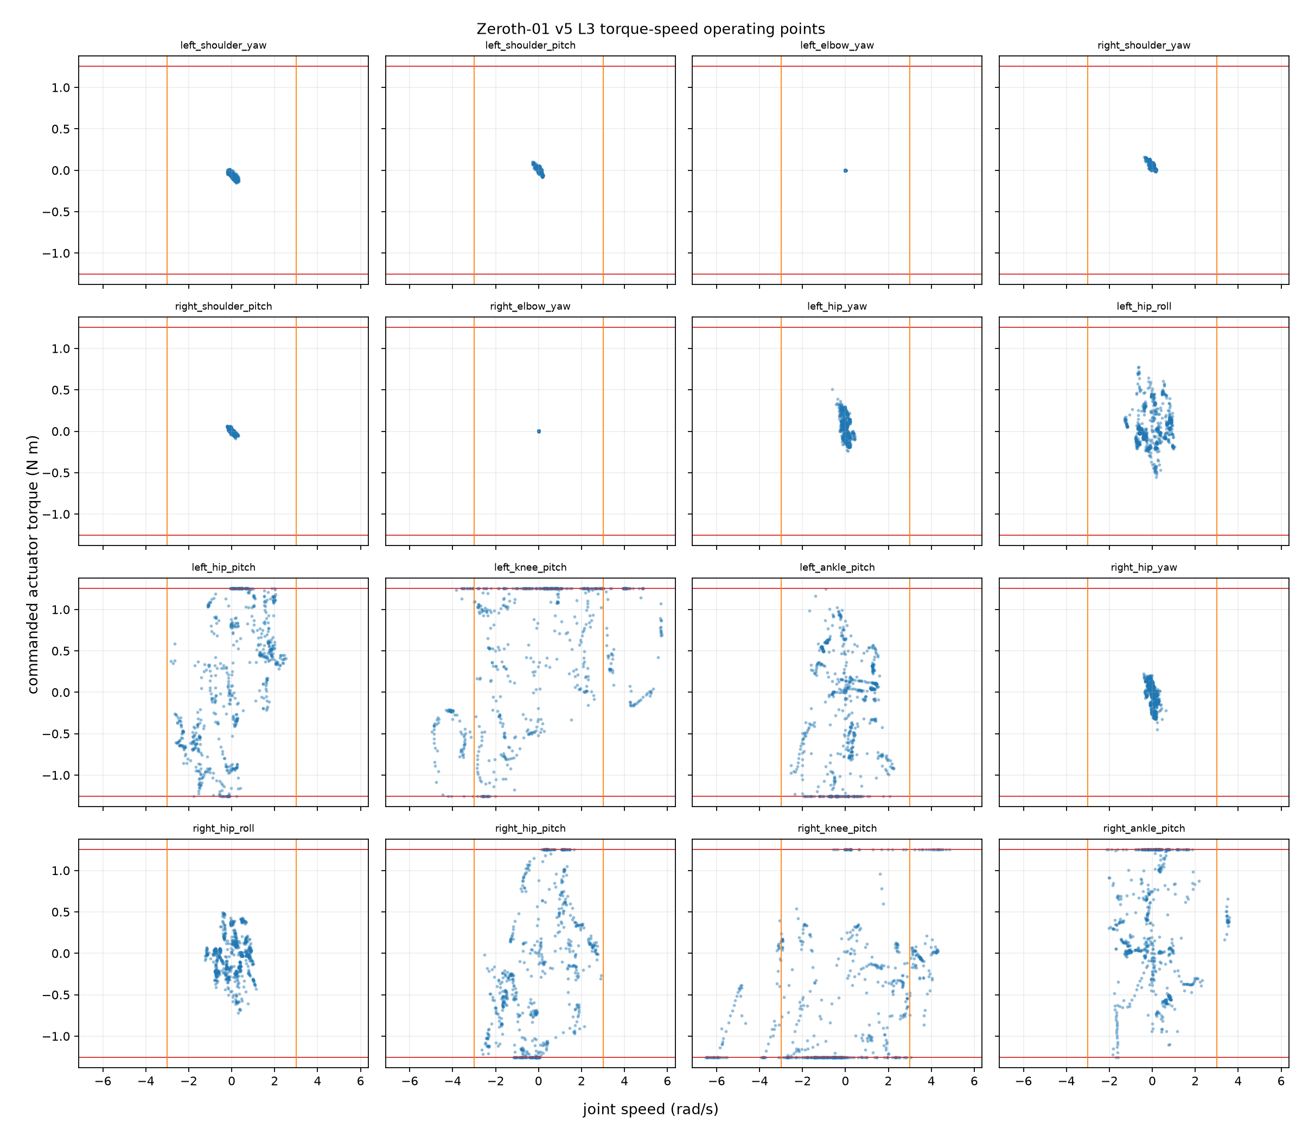
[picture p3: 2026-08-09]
reports/rl_training/v5_16dof_20260809/L3_joint_torque_speed.png

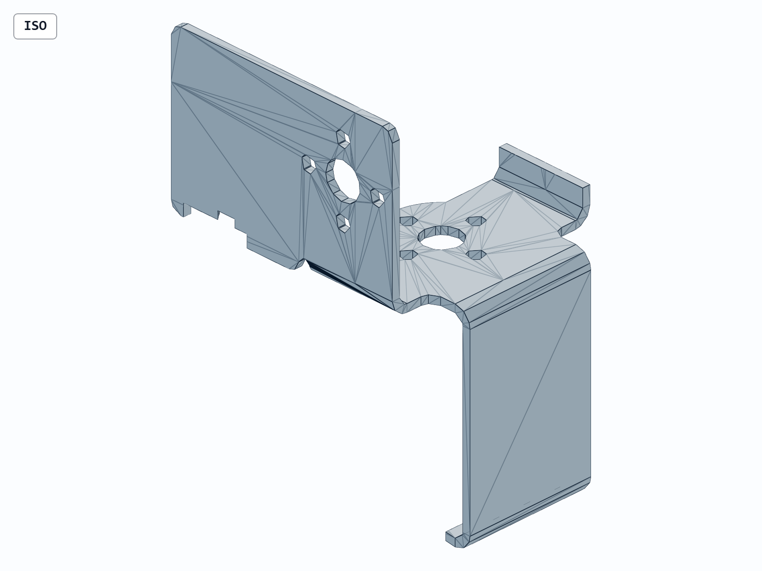
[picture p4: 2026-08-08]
reports/v5_original_16dof_solidworks_motion/snapshots/uhip_mount_clearanced_iso_20260808T193829Z.png

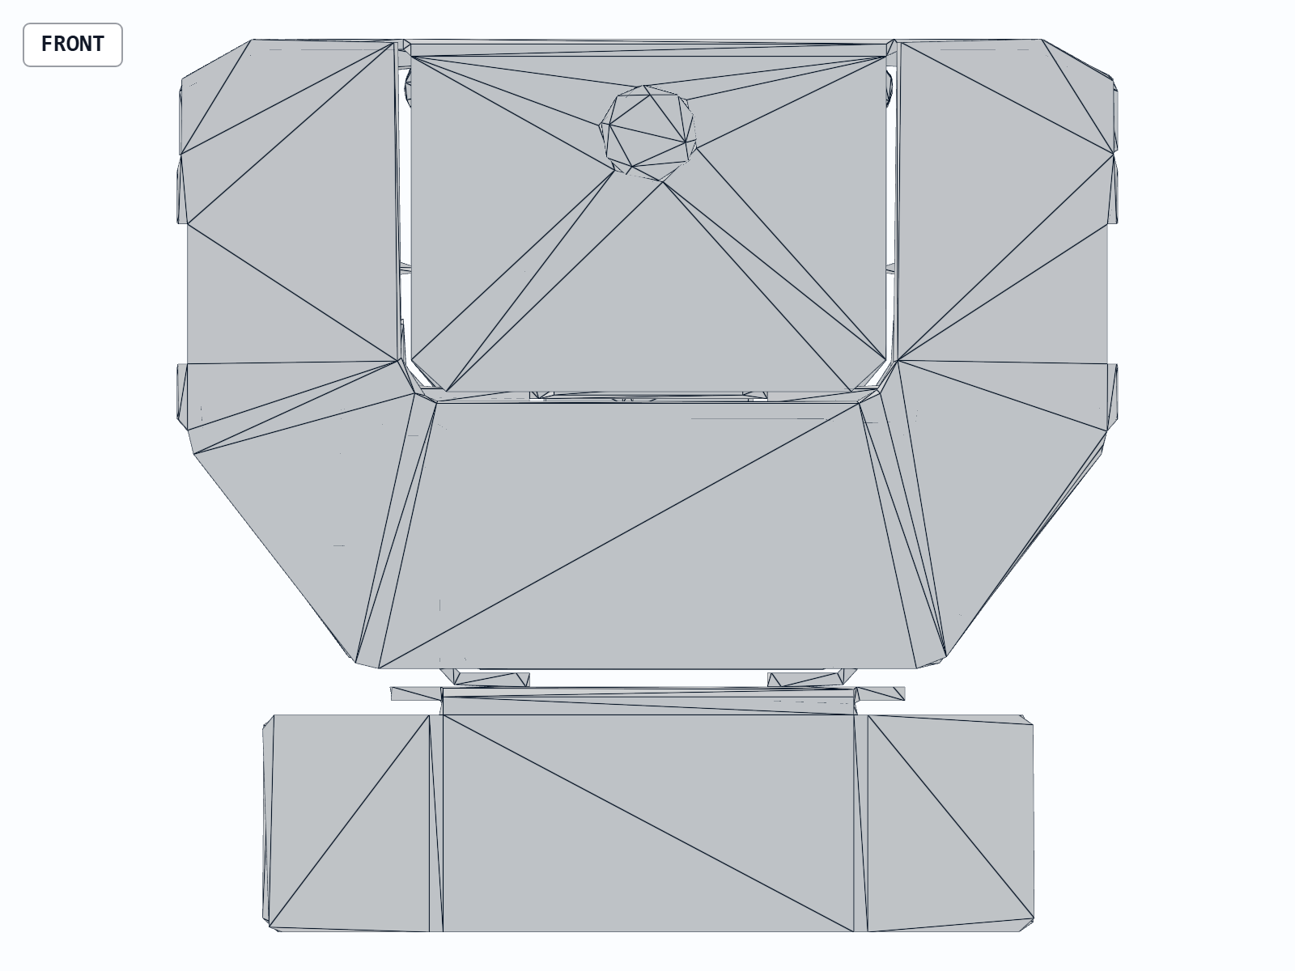
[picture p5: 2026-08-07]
reports/v4_original_minimal/audit/body_no_head_front_20260807T204403Z.png

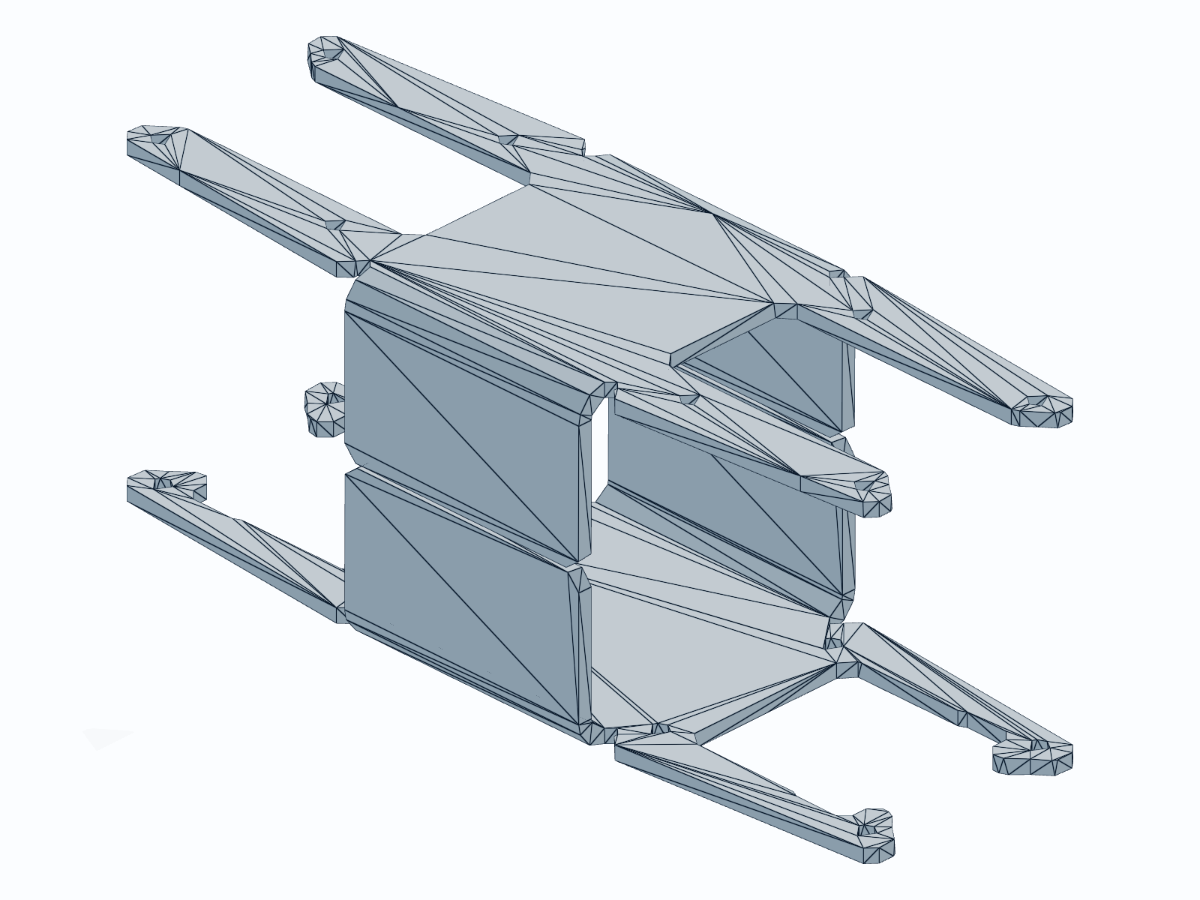
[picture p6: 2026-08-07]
reports/v4_original_minimal/audit/lower_leg_source_iso_20260807T202200Z.png

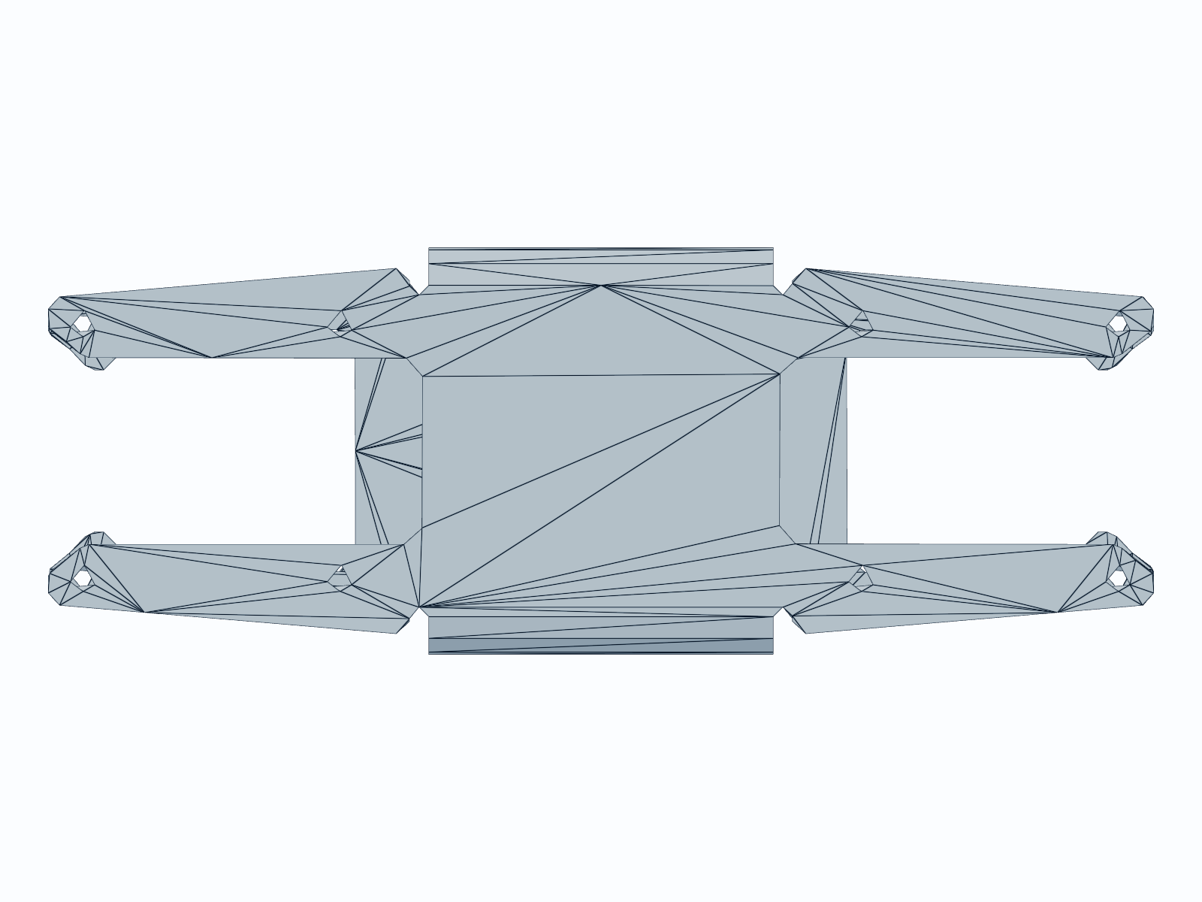
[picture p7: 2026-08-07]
reports/v4_original_minimal/audit/lower_leg_source_top_20260807T202305Z.png

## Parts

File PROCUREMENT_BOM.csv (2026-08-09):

item | manufacturer | model_or_spec | qty | nominal_mass_each_kg | mechanical_interface | status | source
actuator | FEETECH | STS3250-C001 | 16 | 0.0745 | official exact envelope; rear M2 case mount; 25T/OD5.9; PCD14 4xM3 output | WALKING_BASELINE_RUNNING_HOLD | https://www.feetechrc.com/en/562636.html
head_interaction | M5Stack | UnitV2 GC2145 | 1 | 0.018 | 48x18.5x24 mm; removable cradle; camera + microphone | SELECTED | https://shop.m5stack.com/products/unitv2-ai-camera-gc2145
head_shell | custom | front/rear printable shell + visor + M3 nut plate | 1 | 0.055 | direct no-neck torso interface; +5 mm every side; small fillets | FIRST_ARTICLE_PRINT_RELEASE | manufacturing/v5_bambu_first_article_release/3mf
compute_module | Raspberry Pi | Zero 2 W | 1 | 0.012 | 65x30 mm; internal torso tray; 5 V power | SELECTED | https://www.raspberrypi.com/products/raspberry-pi-zero-2-w/
battery_pack | Power-Xtra | PX850XT3S 3S 11.1 V 850 mAh 80C XT30 | 2 | 0.099 | 69.5x32.5x20.9 mm; internal torso cage; fuse and strain relief | SELECTED_DIMENSION_CONTROLLED | https://www.promodelhobby.com/urun/power-xtra-11-1v-850-mah-80c-li-polymer-pil
torso_imu | Adafruit | BNO085 PID 4754 | 1 | 0.0025 | 25.6x22.7x4.6 mm; rigid torso shelf; calibrated transform | SELECTED | https://www.adafruit.com/product/4754
servo_io | Waveshare | Bus Servo Adapter A SKU25514 | 1 |  | 42x33 mm; 9-12.6 V UART; external fused power injection | SELECTED | https://www.waveshare.com/product/modules/motors-servos/bus-servo-adapter-a.htm
logic_regulator | Pololu | D24V50F5 5 V 5 A | 1 | 0.003 | 17.8x20.3x8.9 mm; 6-38 V input; logic/camera rail | SELECTED_EQUIVALENT_ALLOWED | https://www.pololu.com/product/2851/specs
hip_yaw_mount | custom | torso-integrated ribs/bosses plus 2xM2x8 per side | 2 |  | official rear-case pattern; unchanged axis; no floating backplate | FIRST_ARTICLE_HOLD | generated/cad/physical_mount_v5_original_16dof_solidworks_motion/parts
output_bridge | custom | 6061-T6 OD19.95 ID6.2 4xD3.2 PCD14 t2.05 | 16 |  | final powered torque path; plastic file only checks fit | CUSTOM_QUOTE_AFTER_FIT | manufacturing/v5_bambu_first_article_release/fit_check_only/04_sts3250_pcd14_output_bridge_2p05mm.step
parent_thrust_ring | custom | POM/6061 OD25 ID20.4 t2.0 | 16 |  | parent-side thrust interface | CUSTOM_QUOTE_AFTER_FIT | manufacturing/v5_bambu_first_article_release/fit_check_only/02_sts3250_parent_thrust_ring_2mm.step
hip_yaw_spacer | custom | metal sleeve OD4 ID3 L1.65 | 8 |  | four per hip yaw | CUSTOM_QUOTE_AFTER_FIT | manufacturing/v5_bambu_first_article_release/fit_check_only/03_sts3250_pcd14_four_sleeve_spacer_1p65mm_z0p30.step
wrist_support | custom | compact rounded two-M3 fixed support | 2 | 0.0060616 | no claw/gripper/large palm | FIRST_ARTICLE_PRINT_RELEASE | manufacturing/v5_bambu_first_article_release/3mf
sole | custom | 9 mm tapered lower-wider replaceable sole | 2 | 0.0618177 | four M3 clearance holes; add measured 2 mm anti-slip pad | FIRST_ARTICLE_PRINT_RELEASE | manufacturing/v5_bambu_first_article_release/3mf
fasteners | standard | M2/M3 screws washers locknuts and heat-set inserts | 1 |  | freeze lengths after first printed stack measurement | STACK_CHECK_REQUIRED | manufacturing/v5_bambu_first_article_release/PURCHASE_BOM.csv
power_bus | system | 3S direct servo bus; 20 A fuse; fused branches; physical disconnect | 1 |  | wire gauge from measured rollout current and voltage drop | FIRST_ARTICLE_ELECTRICAL_HOLD | manufacturing/v5_bambu_first_article_release/PURCHASE_BOM.csv
harness | system | servo bus power USB sensor and STEMMA QT wiring | 1 |  | service loops and strain relief; no joint shear crossings | ROUTING_FIRST_ARTICLE_HOLD | manufacturing/v5_bambu_first_article_release/PURCHASE_BOM.csv

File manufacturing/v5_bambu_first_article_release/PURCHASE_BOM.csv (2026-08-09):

category | item | manufacturer_model | qty_final | qty_first_order | status | mechanical_or_electrical_requirement | official_link | purchase_link | notes
ACTUATOR | TTL bus servo | FEETECH STS3250-C001 | 16 | 2 | WALKING_BASELINE_RUNNING_HOLD | 12 V; 50 kg·cm stall; 45.22x24.72x35 mm body family; 25T OD5.9; double shaft; verify exact rear M2 and PCD14 drawing | https://www.feetechrc.com/en/562636.html | https://www.alibaba.com/product-detail/Own-Brand-Feetech-Servo-12V-50KG_1601316856304.html | Buy 2 for torque-speed-current-temperature and fit tests; buy remaining 14 only after pass. Current running policy exceeds speed envelope.
VISION_AUDIO | AI camera with microphone | M5Stack UnitV2 GC2145 | 1 | 1 | SELECTED | 48x18.5x24 mm; 5 V 500 mA; removable head cradle | https://shop.m5stack.com/products/unitv2-ai-camera-gc2145 | https://shop.m5stack.com/products/unitv2-ai-camera-gc2145 | Includes camera and microphone; confirm included 32 GB card/cable with seller.
COMPUTE | onboard Linux compute | Raspberry Pi Zero 2 W | 1 | 1 | SELECTED | 65x30 mm; 5 V supply; fits 70x12x32 mm tray envelope after connector check | https://www.raspberrypi.com/products/raspberry-pi-zero-2-w/ | https://www.raspberrypi.com/products/raspberry-pi-zero-2-w/ | 512 MB is for low-level deployment/telemetry, not local MJX training.
SERVO_IO | TTL bus interface | Waveshare Bus Servo Adapter (A) SKU 25514 | 1 | 1 | SELECTED | 9-12.6 V; UART/USB-C; 42x33 mm; sufficient external power injection required | https://docs.waveshare.com/Bus_Servo_Adapter_A | https://www.waveshare.com/product/modules/motors-servos/bus-servo-adapter-a.htm | Use for signal/control; do not assume its small PCB carries every 16-servo transient without fused branch injection.
IMU | 9-axis fused IMU | Adafruit BNO085 PID 4754 | 1 | 1 | SELECTED | 25.6x22.7x4.6 mm; rigid torso shelf; calibrated transform | https://www.adafruit.com/product/4754 | https://www.adafruit.com/product/4754 | Add one STEMMA QT/Qwiic cable; fix board rigidly, no foam.
POWER_LOGIC | 5 V regulator | Pololu D24V50F5 item 2851 | 1 | 1 | SELECTED_EQUIVALENT_ALLOWED | 6-38 V input; 5 V 5 A; >=15 W thermally continuous in installed airflow | https://www.pololu.com/product/2851/specs | https://www.pololu.com/product/2851 | Official stock can be limited; exact equivalent allowed only after size, ripple, transient and thermal validation.
BATTERY | 3S LiPo with XT30 | Power-Xtra PX850XT3S 11.1 V 850 mAh 80C | 2 | 1 | SELECTED_DIMENSION_CONTROLLED | 69.5x32.5x20.9 mm; must remain <=75x22x34 mm when oriented; XT30; 3S balance lead | https://www.power-xtra.com/en/products?page=9 | https://www.promodelhobby.com/urun/power-xtra-11-1v-850-mah-80c-li-polymer-pil | Buy 1 for first article and 1 spare after fit. Verify dimensions and connector before payment; never charge in robot.
CHARGER | balance/storage charger | SkyRC B6neo SK-100198 | 1 | 1 | SELECTED | 1-6S LiPo; balance and storage modes; requires suitable PD/DC input and XT60-to-XT30 charge lead | https://www.skyrc.com/Charger/b6neo?order=DESC&sort=p.model | https://www.skyrc.com/Charger/b6neo?order=DESC&sort=p.model | Use a LiPo-safe bag/box and supervised charging area.
STORAGE | microSD high endurance | 64 GB UHS-I high-endurance | 1 | 1 | SELECTED | Raspberry Pi OS and logs | https://www.raspberrypi.com/products/raspberry-pi-zero-2-w/ | https://www.raspberrypi.com/products/raspberry-pi-zero-2-w/ | UnitV2 listing normally includes its own 32 GB card; verify package.
MATERIAL | structural filament | Bambu PA6-CF 1 kg | 1 | 1 | SELECTED | 0.6 mm hardened nozzle; dry; 5 walls; 45% gyroid | https://bambulab.cn/zh-cn/filament-guide | https://bambulab.cn/zh-cn/filament-guide | Black structural baseline; paint white only after first-article acceptance.
MATERIAL | cosmetic/service filament | Bambu PETG-HF white 1 kg | 1 | 1 | SELECTED | 0.4 mm nozzle; dry; 4 walls; 25-30% gyroid | https://bambulab.cn/zh-cn/filament/petg-hf | https://bambulab.cn/zh-cn/filament/petg-hf | Head shells and visible service parts.
MATERIAL | visor filament | Bambu PETG-HF black | 1 | 1 | SELECTED | 0.4 mm nozzle; only a small quantity is consumed | https://bambulab.cn/zh-cn/filament/petg-hf | https://bambulab.cn/zh-cn/filament/petg-hf | A partial spool is sufficient if available.
METAL_TORQUE | PCD14 output bridge | custom 6061-T6 OD19.95 ID6.2 4xD3.2 PCD14 t2.05 | 16 | 2 | CUSTOM_QUOTE_AFTER_PLASTIC_FIT | Final powered torque path; use fit_check_only/04 STEP | https://jlccnc.com/ | https://jlccnc.com/ | Plastic 3MF is fit-check only. Quote 2 first, then 14 after shaft/PCD check.
METAL_THRUST | parent thrust ring | custom POM or 6061-T6 OD25 ID20.4 t2.0 | 16 | 2 | CUSTOM_QUOTE_AFTER_PLASTIC_FIT | Parent-side axial/thrust interface; use fit_check_only/02 STEP | https://jlccnc.com/ | https://jlccnc.com/ | Deburr and keep bearing face flat.
METAL_SPACER | hip-yaw sleeve | custom metal OD4 ID3 L1.65 | 8 | 8 | CUSTOM_QUOTE_AFTER_PLASTIC_FIT | Four per hip yaw; use fit_check_only/03 STEP | https://jlccnc.com/ | https://jlccnc.com/ | Machine/grind to matched thickness; do not use printed sleeves for power.
FASTENER | M3 socket head screw | ISO 4762 M3x6 | 80 | 20 | STACK_CHECK_REQUIRED | PCD14 and carrier fastening; verify effective thread engagement | https://www.mcmaster.com/products/socket-head-screws/ | https://www.mcmaster.com/products/socket-head-screws/ | Final count/length must follow first printed stack measurement.
FASTENER | M3 socket head screw | ISO 4762 M3x8 | 20 | 10 | STACK_CHECK_REQUIRED | Joint/sole mounting | https://www.mcmaster.com/products/socket-head-screws/ | https://www.mcmaster.com/products/socket-head-screws/ | Buy class 12.9 or stainless only where appropriate; use threadlocker per joint procedure.
FASTENER | M3 socket head screw | ISO 4762 M3x12 | 20 | 10 | STACK_CHECK_REQUIRED | Body/head/sole stack | https://www.mcmaster.com/products/socket-head-screws/ | https://www.mcmaster.com/products/socket-head-screws/ | Measure before full order.
FASTENER | M3 socket head screw | ISO 4762 M3x30 | 6 | 4 | STACK_CHECK_REQUIRED | Long body/head stack where specified | https://www.mcmaster.com/products/socket-head-screws/ | https://www.mcmaster.com/products/socket-head-screws/ | Measure before full order.
FASTENER | M2 socket head assortment | M2x6 M2x8 M2x10 | 130 | 40 | STACK_CHECK_REQUIRED | STS3250 rear-case and small service mounts; minimum M2x8 quantity 8 for hip yaw | https://www.mcmaster.com/products/socket-head-screws/ | https://www.mcmaster.com/products/socket-head-screws/ | Suggested split 50/50/30; exact count after one carrier build.
FASTENER | M2.5 socket head screw | M2.5x8 | 20 | 8 | STACK_CHECK_REQUIRED | electronics board mounts | https://www.mcmaster.com/products/socket-head-screws/ | https://www.mcmaster.com/products/socket-head-screws/ | Use nylon washer where PCB clearance requires.
FASTENER | M3 washer and nyloc nut | M3 | 100/50 | 20/10 | SELECTED | Joint fastening and service covers | https://www.mcmaster.com/products/metric-washers/ | https://www.mcmaster.com/products/metric-washers/ | Do not stack washers to replace precision torque-path spacers.
INSERT | M3 heat-set insert | OD4.6xL5 nominal | 30 | 10 | COUPON_CHECK_REQUIRED | PETG/PA6 printed bosses | https://www.mcmaster.com/products/inserts/heat-set-inserts-for-plastic/ | https://www.mcmaster.com/products/inserts/heat-set-inserts-for-plastic/ | Print an insert coupon and tune hole compensation/temperature first.
POWER_DIST | main fuse and holder | 20 A automotive blade or resettable equivalent | 1 | 1 | SELECTED | Within 100 mm of battery positive; >=20 A wiring rating | https://www.littelfuse.com/products/fuses/automotive-passenger-car/blade-fuses | https://www.littelfuse.com/products/fuses/automotive-passenger-car/blade-fuses | Final rating must be revisited after measured stall/branch current.
POWER_DIST | physical emergency stop / master disconnect | latching DC-rated >=20 A | 1 | 1 | SELECTED | break battery positive; accessible without reaching through robot | https://www.mouser.com/c/electromechanical/switches/emergency-stop-switches-safety-switches/ | https://www.mouser.com/c/electromechanical/switches/emergency-stop-switches-safety-switches/ | Bench first article may use removable XT30 as master disconnect, but final robot needs a guarded physical control.
HARNESS | power wire | silicone 16 AWG red/black | 2 m | 2 m | SELECTED | battery and trunk; voltage-drop and temperature test | https://www.digikey.com/en/products/filter/single-conductor-cables-hook-up-wire/474 | https://www.digikey.com/en/products/filter/single-conductor-cables-hook-up-wire/474 | Use crimped/soldered strain-relieved joints and fused branches.
HARNESS | branch wire | silicone 20 AWG red/black | 4 m | 2 m | SELECTED | servo branches; keep out of joint shear planes | https://www.digikey.com/en/products/filter/single-conductor-cables-hook-up-wire/474 | https://www.digikey.com/en/products/filter/single-conductor-cables-hook-up-wire/474 | Size again from measured branch current and run length.
HARNESS | servo extension/branch | FEETECH ST-series 3-pin 5264/2.54-compatible | 1 set | 1 set | CONNECTOR_SAMPLE_REQUIRED | polarity and pin pitch verified against purchased STS3250 | https://www.feetechrc.com/en/562636.html | https://www.feetechrc.com/en/562636.html | Order connector samples before making full harness; do not trust color alone.
HARNESS | battery connectors | XT30 male/female genuine or AMASS equivalent | 6 pairs | 3 pairs | SELECTED | battery, fuse, removable branches | https://www.amass.com.cn/ | https://www.amass.com.cn/ | Add heat-shrink and strain relief.
FOOT | anti-slip pad | 2 mm rubber or TPU95A adhesive sheet | 1 sheet | 1 sheet | CUT_AFTER_PRINT | cut to sole outline; update contact height in URDF if thickness changes nominal sole plane | https://bambulab.cn/zh-cn/filament-guide | https://bambulab.cn/zh-cn/filament-guide | Do not hide thickness from RL contact model.
FINISH | nylon-compatible primer and white topcoat | local paint system | 1 set | 0 | OPTIONAL_AFTER_FIRST_ARTICLE | only after fit/motion pass; mask joint interfaces, threads and bearing faces |  |  | Do not paint before measuring and dry-fit.

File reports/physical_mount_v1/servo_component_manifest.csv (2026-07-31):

id | joint | source_joint | owning_link | source_mesh | region_id | chain_role | output_mesh | source_region_triangles | source_region_points | bounds_m | center_m_in_owning_link | size_mm | family_envelope_gate | source_sha256 | output_sha256 | mounting_semantics
S01 | right_shoulder_pitch | right_shoulder_pitch | 3215_1Flange_2 | 3215_1Flange_2.stl | 1 | proximal servo body carried by the shoulder-pitch child link | generated/cad/physical_mount_v1/servos/S01_right_shoulder_pitch_INSTALLED_STS3215_FAMILY.stl | 4056 | 2014 | [-0.010111286, 0.035111472, -0.012361288, 0.012361288, -0.03739972, -0.0] | [0.012500093, 0.0, -0.01869986] | [45.222758, 24.722576, 37.39972] | PASS | 0ab617ab3f45d9369d6bf63d7de428ae3fc392e7e14d9ae3c241590714a355dd | 78b50e09ef4d09e21b0e62a67bb3fff62f34ca144fa18deeacbfd20bb671a51c | EXTRACTED_IN_PLACE_FROM_ORIGINAL_ASSEMBLED_ZEROTH_LINK; NO_TRANSLATION_OR_HOUSING_PHASE_ADDED
S02 | left_shoulder_pitch | left_shoulder_pitch | 3215_1Flange | 3215_1Flange.stl | 1 | proximal servo body carried by the shoulder-pitch child link | generated/cad/physical_mount_v1/servos/S02_left_shoulder_pitch_INSTALLED_STS3215_FAMILY.stl | 4052 | 2012 | [-0.010111286, 0.035111472, -0.012361288, 0.012361288, -0.03739972, -0.0] | [0.012500093, 0.0, -0.01869986] | [45.222758, 24.722576, 37.39972] | PASS | 7b6b03b4047961576d2edb3702af5d8cd9e817182e6687919ddffd985f004567 | 11249af4c1173258a2e73d7de6f89a3e6d56db475396ad9bb80532736b9eb36d | EXTRACTED_IN_PLACE_FROM_ORIGINAL_ASSEMBLED_ZEROTH_LINK; NO_TRANSLATION_OR_HOUSING_PHASE_ADDED
S03 | right_shoulder_yaw | right_shoulder_yaw | Z_BOT2_MASTER_BODY_SKELETON | Z_BOT2_MASTER_BODY_SKELETON.stl | 11 | torso-fixed shoulder-yaw servo body | generated/cad/physical_mount_v1/servos/S03_right_shoulder_yaw_INSTALLED_STS3215_FAMILY.stl | 994 | 452 | [-0.066000246, -0.020883502, -0.00960999, 0.027789729, -0.0218891, 0.005981851] | [-0.043441874, 0.009089869, -0.007953624] | [45.116743, 37.399719, 27.870951] | PASS | 405959cb8cbab7b8a7d42a44a5e68dc0232388d579ac5c770beb290b418c59cb | 47bfd4aac4bf6f803303c85982d5e212da42a959aa238f320c9ac0489e48b508 | EXTRACTED_IN_PLACE_FROM_ORIGINAL_ASSEMBLED_ZEROTH_LINK; NO_TRANSLATION_OR_HOUSING_PHASE_ADDED
S04 | right_hip_pitch | right_hip_pitch | 3215_BothFlange_10 | 3215_BothFlange_10.stl | 1 | hip-pitch servo body carried by the hip-pitch child link | generated/cad/physical_mount_v1/servos/S04_right_hip_pitch_INSTALLED_STS3215_FAMILY.stl | 7572 | 3764 | [-0.010111286, 0.035111431, -0.012361288, 0.012361288, -0.03739972, -0.0] | [0.012500072, 0.0, -0.01869986] | [45.222717, 24.722576, 37.39972] | PASS | ec6b1764b7aa9daa277edd69279e3251ce28201b4329a6fd58f642802d73e8c7 | 9264993aff08cd444a44d349b0aa0ba40dd79cedba3e2bbfbca6394084f879ca | EXTRACTED_IN_PLACE_FROM_ORIGINAL_ASSEMBLED_ZEROTH_LINK; NO_TRANSLATION_OR_HOUSING_PHASE_ADDED
S05 | left_hip_pitch | left_hip_pitch | 3215_BothFlange_9 | 3215_BothFlange_9.stl | 1 | hip-pitch servo body carried by the hip-pitch child link | generated/cad/physical_mount_v1/servos/S05_left_hip_pitch_INSTALLED_STS3215_FAMILY.stl | 7590 | 3773 | [-0.010111286, 0.035111472, -0.012361288, 0.012361288, -0.03739972, -0.0] | [0.012500093, 0.0, -0.01869986] | [45.222758, 24.722576, 37.39972] | PASS | 2cccf4fd8e69476260e6aceb891d6e17f22b21e0c0f358ef58961b1fe9120862 | 6651fbc8521724ae1c0ec328c2607fec36762b6bfcd4bbbcf51f68ffe7c03c0b | EXTRACTED_IN_PLACE_FROM_ORIGINAL_ASSEMBLED_ZEROTH_LINK; NO_TRANSLATION_OR_HOUSING_PHASE_ADDED
S06 | left_shoulder_yaw | left_shoulder_yaw | Z_BOT2_MASTER_BODY_SKELETON | Z_BOT2_MASTER_BODY_SKELETON.stl | 17 | torso-fixed shoulder-yaw servo body | generated/cad/physical_mount_v1/servos/S06_left_shoulder_yaw_INSTALLED_STS3215_FAMILY.stl | 984 | 447 | [0.020883737, 0.066000298, -0.009609988, 0.027664732, -0.0218891, 0.005981851] | [0.043442017, 0.009027372, -0.007953624] | [45.116561, 37.27472, 27.870951] | PASS | 405959cb8cbab7b8a7d42a44a5e68dc0232388d579ac5c770beb290b418c59cb | 155d1588f20a34d93d59f8c23b0296f217b2a419096439e9824a13dafa301f92 | EXTRACTED_IN_PLACE_FROM_ORIGINAL_ASSEMBLED_ZEROTH_LINK; NO_TRANSLATION_OR_HOUSING_PHASE_ADDED
S07 | right_hip_yaw | right_hip_yaw | Z_BOT2_MASTER_BODY_SKELETON | Z_BOT2_MASTER_BODY_SKELETON.stl | 5 | torso-fixed hip-yaw servo body | generated/cad/physical_mount_v1/servos/S07_right_hip_yaw_INSTALLED_STS3215_FAMILY.stl | 774 | 365 | [-0.052873407, -0.007756663, -0.004626211, 0.020096365, -0.121693149, -0.084418431] | [-0.030315035, 0.007735077, -0.10305579] | [45.116743, 24.722576, 37.274718] | PASS | 405959cb8cbab7b8a7d42a44a5e68dc0232388d579ac5c770beb290b418c59cb | 00ad02586dbe94c8537503476a1598542f14bbcd58332c8cb198040e1073597f | EXTRACTED_IN_PLACE_FROM_ORIGINAL_ASSEMBLED_ZEROTH_LINK; NO_TRANSLATION_OR_HOUSING_PHASE_ADDED
S08 | left_hip_yaw | left_hip_yaw | Z_BOT2_MASTER_BODY_SKELETON | Z_BOT2_MASTER_BODY_SKELETON.stl | 6 | torso-fixed hip-yaw servo body | generated/cad/physical_mount_v1/servos/S08_left_hip_yaw_INSTALLED_STS3215_FAMILY.stl | 784 | 370 | [0.007696751, 0.052813496, -0.004626211, 0.020096365, -0.121693149, -0.084418431] | [0.030255124, 0.007735077, -0.10305579] | [45.116745, 24.722576, 37.274718] | PASS | 405959cb8cbab7b8a7d42a44a5e68dc0232388d579ac5c770beb290b418c59cb | e89c57a95eff1582b07c6e4b698202ebc8e3d53b939132231bc98a1f146cce6e | EXTRACTED_IN_PLACE_FROM_ORIGINAL_ASSEMBLED_ZEROTH_LINK; NO_TRANSLATION_OR_HOUSING_PHASE_ADDED
S09 | right_elbow_yaw | right_elbow | 3215_1Flange_2 | 3215_1Flange_2.stl | 0 | distal elbow servo body carried by the upper-arm link | generated/cad/physical_mount_v1/servos/S09_right_elbow_yaw_INSTALLED_STS3215_FAMILY.stl | 4844 | 2400 | [0.057872325, 0.103095084, -0.018799718, 0.018600002, -0.030961664, -0.006239086] | [0.080483705, -9.9858e-05, -0.018600375] | [45.222759, 37.39972, 24.722578] | PASS | 0ab617ab3f45d9369d6bf63d7de428ae3fc392e7e14d9ae3c241590714a355dd | 777b92d5dfe35ede688a2186a821399696b65e7adb8c6d4048c5391f868e74fe | EXTRACTED_IN_PLACE_FROM_ORIGINAL_ASSEMBLED_ZEROTH_LINK; NO_TRANSLATION_OR_HOUSING_PHASE_ADDED
S10 | left_elbow_yaw | left_elbow | 3215_1Flange | 3215_1Flange.stl | 0 | distal elbow servo body carried by the upper-arm link | generated/cad/physical_mount_v1/servos/S10_left_elbow_yaw_INSTALLED_STS3215_FAMILY.stl | 4846 | 2401 | [0.057872321, 0.103095077, -0.018600004, 0.018799717, -0.030961664, -0.006239087] | [0.080483699, 9.9856e-05, -0.018600376] | [45.222756, 37.39972, 24.722577] | PASS | 7b6b03b4047961576d2edb3702af5d8cd9e817182e6687919ddffd985f004567 | c94bb62302d7f701e7782eca49485b16e70775b73b3b1bccd27491ad841859fc | EXTRACTED_IN_PLACE_FROM_ORIGINAL_ASSEMBLED_ZEROTH_LINK; NO_TRANSLATION_OR_HOUSING_PHASE_ADDED
S11 | right_hip_roll | right_hip_roll | 3215_BothFlange_6 | 3215_BothFlange_6.stl | 1 | hip-roll servo body carried by the hip-roll child link | generated/cad/physical_mount_v1/servos/S11_right_hip_roll_INSTALLED_STS3215_FAMILY.stl | 8900 | 4428 | [-0.010111286, 0.035111472, -0.012361288, 0.012361288, -0.03739972, -0.0] | [0.012500093, 0.0, -0.01869986] | [45.222758, 24.722576, 37.39972] | PASS | 21f00f20bfd4925abb59ada71a8704a0d44c66ae8e39154ab2d14cd2f3955e67 | d478e5af6644fce52b504aa29c1fc7267a06ac767e364562195cb33baae0eca5 | EXTRACTED_IN_PLACE_FROM_ORIGINAL_ASSEMBLED_ZEROTH_LINK; NO_TRANSLATION_OR_HOUSING_PHASE_ADDED
S12 | left_hip_roll | left_hip_roll | 3215_BothFlange_5 | 3215_BothFlange_5.stl | 1 | hip-roll servo body carried by the hip-roll child link | generated/cad/physical_mount_v1/servos/S12_left_hip_roll_INSTALLED_STS3215_FAMILY.stl | 8900 | 4428 | [-0.010111286, 0.035111472, -0.012361288, 0.012361288, -0.036599718, 0.000800001] | [0.012500093, 0.0, -0.017899859] | [45.222758, 24.722576, 37.399719] | PASS | 97568c164c6daae7d1598bb5b9c4843a3f6a34d4b498ac6cb5f762c59be8398f | 034db8e76390d2697e8ecdf0db482780e614ed7fcd743c86cb25f9d7a1634966 | EXTRACTED_IN_PLACE_FROM_ORIGINAL_ASSEMBLED_ZEROTH_LINK; NO_TRANSLATION_OR_HOUSING_PHASE_ADDED
S13 | right_knee_pitch | right_knee | 3215_BothFlange_14 | 3215_BothFlange_14.stl | 1 | proximal knee servo body carried by the lower-leg link | generated/cad/physical_mount_v1/servos/S13_right_knee_pitch_INSTALLED_STS3215_FAMILY.stl | 4498 | 2227 | [-0.010111286, 0.035111472, -0.012361288, 0.012361288, -0.03739972, -0.0] | [0.012500093, 0.0, -0.01869986] | [45.222758, 24.722576, 37.39972] | PASS | 797195b92821f85a83d4c9e335fae750b0baea982fe6fca96293b900deb7b67d | 38d04ece2818f12dd9646698843cd6104eca7732d28cced3d263bace11c1a5ff | EXTRACTED_IN_PLACE_FROM_ORIGINAL_ASSEMBLED_ZEROTH_LINK; NO_TRANSLATION_OR_HOUSING_PHASE_ADDED
S14 | left_knee_pitch | left_knee | 3215_BothFlange_13 | 3215_BothFlange_13.stl | 1 | proximal knee servo body carried by the lower-leg link | generated/cad/physical_mount_v1/servos/S14_left_knee_pitch_INSTALLED_STS3215_FAMILY.stl | 4496 | 2226 | [-0.010111286, 0.035111472, -0.012361288, 0.012361288, -0.03739972, -0.0] | [0.012500093, 0.0, -0.01869986] | [45.222758, 24.722576, 37.39972] | PASS | 558f7a5f7e94f4b9bb44e0237e8c99c0c8c6686ed068f59fc53f9ba7f34324e4 | 068070e5e5696e8a276e470e8b715fe45de8b98682a089896d22fd34a57b1cf3 | EXTRACTED_IN_PLACE_FROM_ORIGINAL_ASSEMBLED_ZEROTH_LINK; NO_TRANSLATION_OR_HOUSING_PHASE_ADDED
S15 | right_ankle_pitch | right_ankle | 3215_BothFlange_14 | 3215_BothFlange_14.stl | 0 | distal ankle servo body carried by the lower-leg link | generated/cad/physical_mount_v1/servos/S15_right_ankle_pitch_INSTALLED_STS3215_FAMILY.stl | 4500 | 2228 | [0.064888529, 0.110111289, -0.012361288, 0.012361291, -0.037399717, 5e-09] | [0.087499909, 1e-09, -0.018699856] | [45.222759, 24.722579, 37.399722] | PASS | 797195b92821f85a83d4c9e335fae750b0baea982fe6fca96293b900deb7b67d | af5f4d28cbcb8a47ade8a072f1e663ba08c2f29dacf20125eedf66e1b08a3d82 | EXTRACTED_IN_PLACE_FROM_ORIGINAL_ASSEMBLED_ZEROTH_LINK; NO_TRANSLATION_OR_HOUSING_PHASE_ADDED
S16 | left_ankle_pitch | left_ankle | 3215_BothFlange_13 | 3215_BothFlange_13.stl | 0 | distal ankle servo body carried by the lower-leg link | generated/cad/physical_mount_v1/servos/S16_left_ankle_pitch_INSTALLED_STS3215_FAMILY.stl | 4498 | 2227 | [0.064888529, 0.110111289, -0.012361288, 0.012361291, -0.037599716, -0.000199995] | [0.087499909, 1e-09, -0.018899856] | [45.222759, 24.722579, 37.399721] | PASS | 558f7a5f7e94f4b9bb44e0237e8c99c0c8c6686ed068f59fc53f9ba7f34324e4 | c5a840e2de40afa70aa26224600b18631c08196e6a98835351472c7591b46ff9 | EXTRACTED_IN_PLACE_FROM_ORIGINAL_ASSEMBLED_ZEROTH_LINK; NO_TRANSLATION_OR_HOUSING_PHASE_ADDED

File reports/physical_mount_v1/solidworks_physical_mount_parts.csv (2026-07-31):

source | part | method | load_error | extent_x_m | extent_y_m | extent_z_m | bytes | seconds | scale_gate | status | kind | link | id | joint | owning_link
E:\Codex\Documents-Codex\roboto-lite-infra-portfolio\roboto_xw\reference\zeroth01\generated\cad\physical_mount_v1\skeleton\3215_1Flange.stl | E:\Codex\Documents-Codex\roboto-lite-infra-portfolio\roboto_xw\reference\zeroth01\generated\solidworks\physical_mount_v1\parts\skeleton\ZEROTH01_PHYSICAL_MOUNT_V1_3215_1FLANGE_CARRIER.SLDPRT | reuse_existing_interactive_stl_surface_part | 0 | 0.10662976279854774 | 0.035040002316236496 | 0.035040000337176025 | 679461 | 3.863532543182373 | PASS | PASS | carrier | 3215_1Flange
E:\Codex\Documents-Codex\roboto-lite-infra-portfolio\roboto_xw\reference\zeroth01\generated\cad\physical_mount_v1\skeleton\3215_1Flange_2.stl | E:\Codex\Documents-Codex\roboto-lite-infra-portfolio\roboto_xw\reference\zeroth01\generated\solidworks\physical_mount_v1\parts\skeleton\ZEROTH01_PHYSICAL_MOUNT_V1_3215_1FLANGE_2_CARRIER.SLDPRT | reuse_existing_interactive_stl_surface_part | 0 | 0.10662976279854774 | 0.035040002316236496 | 0.035040000337176025 | 682711 | 1.0865027904510498 | PASS | PASS | carrier | 3215_1Flange_2
E:\Codex\Documents-Codex\roboto-lite-infra-portfolio\roboto_xw\reference\zeroth01\generated\cad\physical_mount_v1\skeleton\3215_BothFlange_10.stl | E:\Codex\Documents-Codex\roboto-lite-infra-portfolio\roboto_xw\reference\zeroth01\generated\solidworks\physical_mount_v1\parts\skeleton\ZEROTH01_PHYSICAL_MOUNT_V1_3215_BOTHFLANGE_10_CARRIER.SLDPRT | reuse_existing_interactive_stl_surface_part | 0 | 0.10451276833191514 | 0.03684866987168789 | 0.04064000165089965 | 1228182 | 1.1239137649536133 | PASS | PASS | carrier | 3215_BothFlange_10
E:\Codex\Documents-Codex\roboto-lite-infra-portfolio\roboto_xw\reference\zeroth01\generated\cad\physical_mount_v1\skeleton\3215_BothFlange_13.stl | E:\Codex\Documents-Codex\roboto-lite-infra-portfolio\roboto_xw\reference\zeroth01\generated\solidworks\physical_mount_v1\parts\skeleton\ZEROTH01_PHYSICAL_MOUNT_V1_3215_BOTHFLANGE_13_CARRIER.SLDPRT | reuse_existing_interactive_stl_surface_part | 0 | 0.08907703449949622 | 0.032759977504611015 | 0.03484000253956765 | 633100 | 1.0643706321716309 | PASS | PASS | carrier | 3215_BothFlange_13
E:\Codex\Documents-Codex\roboto-lite-infra-portfolio\roboto_xw\reference\zeroth01\generated\cad\physical_mount_v1\skeleton\3215_BothFlange_14.stl | E:\Codex\Documents-Codex\roboto-lite-infra-portfolio\roboto_xw\reference\zeroth01\generated\solidworks\physical_mount_v1\parts\skeleton\ZEROTH01_PHYSICAL_MOUNT_V1_3215_BOTHFLANGE_14_CARRIER.SLDPRT | reuse_existing_interactive_stl_surface_part | 0 | 0.08907703449949622 | 0.032759975641965866 | 0.03504000254906714 | 630442 | 1.081622838973999 | PASS | PASS | carrier | 3215_BothFlange_14
E:\Codex\Documents-Codex\roboto-lite-infra-portfolio\roboto_xw\reference\zeroth01\generated\cad\physical_mount_v1\skeleton\3215_BothFlange_5.stl | E:\Codex\Documents-Codex\roboto-lite-infra-portfolio\roboto_xw\reference\zeroth01\generated\solidworks\physical_mount_v1\parts\skeleton\ZEROTH01_PHYSICAL_MOUNT_V1_3215_BOTHFLANGE_5_CARRIER.SLDPRT | reuse_existing_interactive_stl_surface_part | 0 | 0.044025651179254055 | 0.05480293929576874 | 0.03504000077373348 | 578248 | 1.0730574131011963 | PASS | PASS | carrier | 3215_BothFlange_5
E:\Codex\Documents-Codex\roboto-lite-infra-portfolio\roboto_xw\reference\zeroth01\generated\cad\physical_mount_v1\skeleton\3215_BothFlange_6.stl | E:\Codex\Documents-Codex\roboto-lite-infra-portfolio\roboto_xw\reference\zeroth01\generated\solidworks\physical_mount_v1\parts\skeleton\ZEROTH01_PHYSICAL_MOUNT_V1_3215_BOTHFLANGE_6_CARRIER.SLDPRT | reuse_existing_interactive_stl_surface_part | 0 | 0.044025653041899204 | 0.05480293929576874 | 0.03503999998793006 | 592099 | 1.0372068881988525 | PASS | PASS | carrier | 3215_BothFlange_6
E:\Codex\Documents-Codex\roboto-lite-infra-portfolio\roboto_xw\reference\zeroth01\generated\cad\physical_mount_v1\skeleton\3215_BothFlange_9.stl | E:\Codex\Documents-Codex\roboto-lite-infra-portfolio\roboto_xw\reference\zeroth01\generated\solidworks\physical_mount_v1\parts\skeleton\ZEROTH01_PHYSICAL_MOUNT_V1_3215_BOTHFLANGE_9_CARRIER.SLDPRT | reuse_existing_interactive_stl_surface_part | 0 | 0.104512769728899 | 0.03684866987168789 | 0.040639999555423856 | 1260040 | 1.0925624370574951 | PASS | PASS | carrier | 3215_BothFlange_9
E:\Codex\Documents-Codex\roboto-lite-infra-portfolio\roboto_xw\reference\zeroth01\generated\cad\physical_mount_v1\skeleton\FINGER_1.stl | E:\Codex\Documents-Codex\roboto-lite-infra-portfolio\roboto_xw\reference\zeroth01\generated\solidworks\physical_mount_v1\parts\skeleton\ZEROTH01_PHYSICAL_MOUNT_V1_FINGER_1_CARRIER.SLDPRT | reuse_existing_interactive_stl_surface_part | 0 | 0.026911133900284767 | 0.07625205535441637 | 0.040639999555423856 | 2121297 | 1.141343593597412 | PASS | PASS | carrier | FINGER_1
E:\Codex\Documents-Codex\roboto-lite-infra-portfolio\roboto_xw\reference\zeroth01\generated\cad\physical_mount_v1\skeleton\FINGER_1_2.stl | E:\Codex\Documents-Codex\roboto-lite-infra-portfolio\roboto_xw\reference\zeroth01\generated\solidworks\physical_mount_v1\parts\skeleton\ZEROTH01_PHYSICAL_MOUNT_V1_FINGER_1_2_CARRIER.SLDPRT | reuse_existing_interactive_stl_surface_part | 0 | 0.026911132037639618 | 0.07625205535441637 | 0.040640001418069005 | 2136429 | 1.1465940475463867 | PASS | PASS | carrier | FINGER_1_2
E:\Codex\Documents-Codex\roboto-lite-infra-portfolio\roboto_xw\reference\zeroth01\generated\cad\physical_mount_v1\skeleton\FOOT.stl | E:\Codex\Documents-Codex\roboto-lite-infra-portfolio\roboto_xw\reference\zeroth01\generated\solidworks\physical_mount_v1\parts\skeleton\ZEROTH01_PHYSICAL_MOUNT_V1_FOOT_CARRIER.SLDPRT | reuse_existing_interactive_stl_surface_part | 0 | 0.08995000459253788 | 0.0455683832988143 | 0.04043999977875501 | 1299643 | 1.113480806350708 | PASS | PASS | carrier | FOOT
E:\Codex\Documents-Codex\roboto-lite-infra-portfolio\roboto_xw\reference\zeroth01\generated\cad\physical_mount_v1\skeleton\FOOT_2.stl | E:\Codex\Documents-Codex\roboto-lite-infra-portfolio\roboto_xw\reference\zeroth01\generated\solidworks\physical_mount_v1\parts\skeleton\ZEROTH01_PHYSICAL_MOUNT_V1_FOOT_2_CARRIER.SLDPRT | reuse_existing_interactive_stl_surface_part | 0 | 0.08995000459253788 | 0.045568379573524 | 0.04043999931309372 | 1225844 | 1.0942556858062744 | PASS | PASS | carrier | FOOT_2
E:\Codex\Documents-Codex\roboto-lite-infra-portfolio\roboto_xw\reference\zeroth01\generated\cad\physical_mount_v1\skeleton\IMU.stl | E:\Codex\Documents-Codex\roboto-lite-infra-portfolio\roboto_xw\reference\zeroth01\generated\solidworks\physical_mount_v1\parts\skeleton\ZEROTH01_PHYSICAL_MOUNT_V1_IMU_2_CARRIER.SLDPRT | reuse_existing_interactive_stl_surface_part | 0 | 0.025499999290332198 | 0.02050000079907477 | 0.005200000014156103 | 239688 | 1.064577579498291 | PASS | PASS | carrier | IMU_2
E:\Codex\Documents-Codex\roboto-lite-infra-portfolio\roboto_xw\reference\zeroth01\generated\cad\physical_mount_v1\skeleton\L_ARM_MIRROR_1.stl | E:\Codex\Documents-Codex\roboto-lite-infra-portfolio\roboto_xw\reference\zeroth01\generated\solidworks\physical_mount_v1\parts\skeleton\ZEROTH01_PHYSICAL_MOUNT_V1_L_ARM_MIRROR_1_CARRIER.SLDPRT | reuse_existing_interactive_stl_surface_part | 0 | 0.03976183570921421 | 0.14317752420902252 | 0.04064000037033111 | 4602111 | 1.3580412864685059 | PASS | PASS | carrier | L_ARM_MIRROR_1
E:\Codex\Documents-Codex\roboto-lite-infra-portfolio\roboto_xw\reference\zeroth01\generated\cad\physical_mount_v1\skeleton\R_ARM_MIRROR_1.stl | E:\Codex\Documents-Codex\roboto-lite-infra-portfolio\roboto_xw\reference\zeroth01\generated\solidworks\physical_mount_v1\parts\skeleton\ZEROTH01_PHYSICAL_MOUNT_V1_R_ARM_MIRROR_1_CARRIER.SLDPRT | reuse_existing_interactive_stl_surface_part | 0 | 0.14307752437889576 | 0.03977058734744787 | 0.04064000304788351 | 4754913 | 1.3168509006500244 | PASS | PASS | carrier | R_ARM_MIRROR_1
E:\Codex\Documents-Codex\roboto-lite-infra-portfolio\roboto_xw\reference\zeroth01\generated\cad\physical_mount_v1\skeleton\U_HIP_L.stl | E:\Codex\Documents-Codex\roboto-lite-infra-portfolio\roboto_xw\reference\zeroth01\generated\solidworks\physical_mount_v1\parts\skeleton\ZEROTH01_PHYSICAL_MOUNT_V1_U_HIP_L_CARRIER.SLDPRT | reuse_existing_interactive_stl_surface_part | 0 | 0.053235650062561035 | 0.04043932259082794 | 0.0702799865975976 | 741597 | 1.098658561706543 | PASS | PASS | carrier | U_HIP_L
E:\Codex\Documents-Codex\roboto-lite-infra-portfolio\roboto_xw\reference\zeroth01\generated\cad\physical_mount_v1\skeleton\U_HIP_R.stl | E:\Codex\Documents-Codex\roboto-lite-infra-portfolio\roboto_xw\reference\zeroth01\generated\solidworks\physical_mount_v1\parts\skeleton\ZEROTH01_PHYSICAL_MOUNT_V1_U_HIP_R_CARRIER.SLDPRT | reuse_existing_interactive_stl_surface_part | 0 | 0.053235650062561035 | 0.04043932259082794 | 0.0702799865975976 | 725773 | 1.097560167312622 | PASS | PASS | carrier | U_HIP_R
E:\Codex\Documents-Codex\roboto-lite-infra-portfolio\roboto_xw\reference\zeroth01\generated\cad\physical_mount_v1\skeleton\Z_BOT2_MASTER_BODY_SKELETON.stl | E:\Codex\Documents-Codex\roboto-lite-infra-portfolio\roboto_xw\reference\zeroth01\generated\solidworks\physical_mount_v1\parts\skeleton\ZEROTH01_PHYSICAL_MOUNT_V1_Z_BOT2_MASTER_BODY_SKELETON_CARRIER.SLDPRT | reuse_existing_interactive_stl_surface_part | 0 | 0.1346050575375557 | 0.10376729816198349 | 0.1893593892455101 | 3207402 | 1.3142902851104736 | PASS | PASS | carrier | Z_BOT2_MASTER_BODY_SKELETON
E:\Codex\Documents-Codex\roboto-lite-infra-portfolio\roboto_xw\reference\zeroth01\generated\cad\physical_mount_v1\skeleton\Z_BOT2_MASTER_SHOULDER2.stl | E:\Codex\Documents-Codex\roboto-lite-infra-portfolio\roboto_xw\reference\zeroth01\generated\solidworks\physical_mount_v1\parts\skeleton\ZEROTH01_PHYSICAL_MOUNT_V1_Z_BOT2_MASTER_SHOULDER2_CARRIER.SLDPRT | reuse_existing_interactive_stl_surface_part | 0 | 0.029785447753965855 | 0.029842346906661987 | 0.04063999990466982 | 651850 | 1.1192283630371094 | PASS | PASS | carrier | Z_BOT2_MASTER_SHOULDER2
E:\Codex\Documents-Codex\roboto-lite-infra-portfolio\roboto_xw\reference\zeroth01\generated\cad\physical_mount_v1\skeleton\Z_BOT2_MASTER_SHOULDER2_2.stl | E:\Codex\Documents-Codex\roboto-lite-infra-portfolio\roboto_xw\reference\zeroth01\generated\solidworks\physical_mount_v1\parts\skeleton\ZEROTH01_PHYSICAL_MOUNT_V1_Z_BOT2_MASTER_SHOULDER2_2_CARRIER.SLDPRT | reuse_existing_interactive_stl_surface_part | 0 | 0.029785447753965855 | 0.02984234690666199 | 0.040640001418069005 | 647112 | 1.0867884159088135 | PASS | PASS | carrier | Z_BOT2_MASTER_SHOULDER2_2
E:\Codex\Documents-Codex\roboto-lite-infra-portfolio\roboto_xw\reference\zeroth01\generated\cad\physical_mount_v1\servos\S01_right_shoulder_pitch_INSTALLED_STS3215_FAMILY.stl | E:\Codex\Documents-Codex\roboto-lite-infra-portfolio\roboto_xw\reference\zeroth01\generated\solidworks\physical_mount_v1\parts\servos\S01_INSTALLED_STS3215_FAMILY_REFERENCE_RIGHT_SHOULDER_PITCH.SLDPRT | reuse_existing_interactive_stl_surface_part | 0 | 0.0452227583155036 | 0.024722576141357422 | 0.03739971995837019 | 2014921 | 1.1352527141571045 | PASS | PASS | servo |  | S01 | right_shoulder_pitch | 3215_1Flange_2
E:\Codex\Documents-Codex\roboto-lite-infra-portfolio\roboto_xw\reference\zeroth01\generated\cad\physical_mount_v1\servos\S02_left_shoulder_pitch_INSTALLED_STS3215_FAMILY.stl | E:\Codex\Documents-Codex\roboto-lite-infra-portfolio\roboto_xw\reference\zeroth01\generated\solidworks\physical_mount_v1\parts\servos\S02_INSTALLED_STS3215_FAMILY_REFERENCE_LEFT_SHOULDER_PITCH.SLDPRT | reuse_existing_interactive_stl_surface_part | 0 | 0.0452227583155036 | 0.024722576141357422 | 0.03739971995837019 | 2015707 | 1.1627330780029297 | PASS | PASS | servo |  | S02 | left_shoulder_pitch | 3215_1Flange
E:\Codex\Documents-Codex\roboto-lite-infra-portfolio\roboto_xw\reference\zeroth01\generated\cad\physical_mount_v1\servos\S03_right_shoulder_yaw_INSTALLED_STS3215_FAMILY.stl | E:\Codex\Documents-Codex\roboto-lite-infra-portfolio\roboto_xw\reference\zeroth01\generated\solidworks\physical_mount_v1\parts\servos\S03_INSTALLED_STS3215_FAMILY_REFERENCE_RIGHT_SHOULDER_YAW.SLDPRT | reuse_existing_interactive_stl_surface_part | 0 | 0.045116743072867393 | 0.037399718537926674 | 0.027870950754731894 | 654615 | 1.1120357513427734 | PASS | PASS | servo |  | S03 | right_shoulder_yaw | Z_BOT2_MASTER_BODY_SKELETON
E:\Codex\Documents-Codex\roboto-lite-infra-portfolio\roboto_xw\reference\zeroth01\generated\cad\physical_mount_v1\servos\S04_right_hip_pitch_INSTALLED_STS3215_FAMILY.stl | E:\Codex\Documents-Codex\roboto-lite-infra-portfolio\roboto_xw\reference\zeroth01\generated\solidworks\physical_mount_v1\parts\servos\S04_INSTALLED_STS3215_FAMILY_REFERENCE_RIGHT_HIP_PITCH.SLDPRT | reuse_existing_interactive_stl_surface_part | 0 | 0.045222717337310314 | 0.024722576141357422 | 0.03739971995837019 | 3710902 | 1.3205599784851074 | PASS | PASS | servo |  | S04 | right_hip_pitch | 3215_BothFlange_10
E:\Codex\Documents-Codex\roboto-lite-infra-portfolio\roboto_xw\reference\zeroth01\generated\cad\physical_mount_v1\servos\S05_left_hip_pitch_INSTALLED_STS3215_FAMILY.stl | E:\Codex\Documents-Codex\roboto-lite-infra-portfolio\roboto_xw\reference\zeroth01\generated\solidworks\physical_mount_v1\parts\servos\S05_INSTALLED_STS3215_FAMILY_REFERENCE_LEFT_HIP_PITCH.SLDPRT | reuse_existing_interactive_stl_surface_part | 0 | 0.0452227583155036 | 0.024722576141357422 | 0.03739971995837019 | 3721481 | 1.3111579418182373 | PASS | PASS | servo |  | S05 | left_hip_pitch | 3215_BothFlange_9
E:\Codex\Documents-Codex\roboto-lite-infra-portfolio\roboto_xw\reference\zeroth01\generated\cad\physical_mount_v1\servos\S06_left_shoulder_yaw_INSTALLED_STS3215_FAMILY.stl | E:\Codex\Documents-Codex\roboto-lite-infra-portfolio\roboto_xw\reference\zeroth01\generated\solidworks\physical_mount_v1\parts\servos\S06_INSTALLED_STS3215_FAMILY_REFERENCE_LEFT_SHOULDER_YAW.SLDPRT | reuse_existing_interactive_stl_surface_part | 0 | 0.04511656053364277 | 0.03727472014725208 | 0.027870950754731894 | 652119 | 1.0967631340026855 | PASS | PASS | servo |  | S06 | left_shoulder_yaw | Z_BOT2_MASTER_BODY_SKELETON
E:\Codex\Documents-Codex\roboto-lite-infra-portfolio\roboto_xw\reference\zeroth01\generated\cad\physical_mount_v1\servos\S07_right_hip_yaw_INSTALLED_STS3215_FAMILY.stl | E:\Codex\Documents-Codex\roboto-lite-infra-portfolio\roboto_xw\reference\zeroth01\generated\solidworks\physical_mount_v1\parts\servos\S07_INSTALLED_STS3215_FAMILY_REFERENCE_RIGHT_HIP_YAW.SLDPRT | reuse_existing_interactive_stl_surface_part | 0 | 0.045116743072867393 | 0.024722576141357422 | 0.037274718284606934 | 522879 | 1.11141037940979 | PASS | PASS | servo |  | S07 | right_hip_yaw | Z_BOT2_MASTER_BODY_SKELETON
E:\Codex\Documents-Codex\roboto-lite-infra-portfolio\roboto_xw\reference\zeroth01\generated\cad\physical_mount_v1\servos\S08_left_hip_yaw_INSTALLED_STS3215_FAMILY.stl | E:\Codex\Documents-Codex\roboto-lite-infra-portfolio\roboto_xw\reference\zeroth01\generated\solidworks\physical_mount_v1\parts\servos\S08_INSTALLED_STS3215_FAMILY_REFERENCE_LEFT_HIP_YAW.SLDPRT | reuse_existing_interactive_stl_surface_part | 0 | 0.04511674540117383 | 0.024722576141357422 | 0.037274718284606934 | 535522 | 1.1026296615600586 | PASS | PASS | servo |  | S08 | left_hip_yaw | Z_BOT2_MASTER_BODY_SKELETON
E:\Codex\Documents-Codex\roboto-lite-infra-portfolio\roboto_xw\reference\zeroth01\generated\cad\physical_mount_v1\servos\S09_right_elbow_yaw_INSTALLED_STS3215_FAMILY.stl | E:\Codex\Documents-Codex\roboto-lite-infra-portfolio\roboto_xw\reference\zeroth01\generated\solidworks\physical_mount_v1\parts\servos\S09_INSTALLED_STS3215_FAMILY_REFERENCE_RIGHT_ELBOW_YAW.SLDPRT | reuse_existing_interactive_stl_surface_part | 0 | 0.04522275924682617 | 0.03739972040057182 | 0.02472257846966386 | 2364258 | 1.2498712539672852 | PASS | PASS | servo |  | S09 | right_elbow_yaw | 3215_1Flange_2
E:\Codex\Documents-Codex\roboto-lite-infra-portfolio\roboto_xw\reference\zeroth01\generated\cad\physical_mount_v1\servos\S10_left_elbow_yaw_INSTALLED_STS3215_FAMILY.stl | E:\Codex\Documents-Codex\roboto-lite-infra-portfolio\roboto_xw\reference\zeroth01\generated\solidworks\physical_mount_v1\parts\servos\S10_INSTALLED_STS3215_FAMILY_REFERENCE_LEFT_ELBOW_YAW.SLDPRT | reuse_existing_interactive_stl_surface_part | 0 | 0.04522275552153587 | 0.03739972040057182 | 0.024722577072679996 | 2394519 | 1.2598474025726318 | PASS | PASS | servo |  | S10 | left_elbow_yaw | 3215_1Flange
E:\Codex\Documents-Codex\roboto-lite-infra-portfolio\roboto_xw\reference\zeroth01\generated\cad\physical_mount_v1\servos\S11_right_hip_roll_INSTALLED_STS3215_FAMILY.stl | E:\Codex\Documents-Codex\roboto-lite-infra-portfolio\roboto_xw\reference\zeroth01\generated\solidworks\physical_mount_v1\parts\servos\S11_INSTALLED_STS3215_FAMILY_REFERENCE_RIGHT_HIP_ROLL.SLDPRT | reuse_existing_interactive_stl_surface_part | 0 | 0.0452227583155036 | 0.024722576141357422 | 0.03739971995837019 | 4364678 | 1.343977689743042 | PASS | PASS | servo |  | S11 | right_hip_roll | 3215_BothFlange_6
E:\Codex\Documents-Codex\roboto-lite-infra-portfolio\roboto_xw\reference\zeroth01\generated\cad\physical_mount_v1\servos\S12_left_hip_roll_INSTALLED_STS3215_FAMILY.stl | E:\Codex\Documents-Codex\roboto-lite-infra-portfolio\roboto_xw\reference\zeroth01\generated\solidworks\physical_mount_v1\parts\servos\S12_INSTALLED_STS3215_FAMILY_REFERENCE_LEFT_HIP_ROLL.SLDPRT | reuse_existing_interactive_stl_surface_part | 0 | 0.0452227583155036 | 0.024722576141357422 | 0.037399718537926674 | 4299786 | 1.324939489364624 | PASS | PASS | servo |  | S12 | left_hip_roll | 3215_BothFlange_5
E:\Codex\Documents-Codex\roboto-lite-infra-portfolio\roboto_xw\reference\zeroth01\generated\cad\physical_mount_v1\servos\S13_right_knee_pitch_INSTALLED_STS3215_FAMILY.stl | E:\Codex\Documents-Codex\roboto-lite-infra-portfolio\roboto_xw\reference\zeroth01\generated\solidworks\physical_mount_v1\parts\servos\S13_INSTALLED_STS3215_FAMILY_REFERENCE_RIGHT_KNEE_PITCH.SLDPRT | reuse_existing_interactive_stl_surface_part | 0 | 0.0452227583155036 | 0.024722576141357422 | 0.03739971995837019 | 2160084 | 1.1542394161224365 | PASS | PASS | servo |  | S13 | right_knee_pitch | 3215_BothFlange_14
E:\Codex\Documents-Codex\roboto-lite-infra-portfolio\roboto_xw\reference\zeroth01\generated\cad\physical_mount_v1\servos\S14_left_knee_pitch_INSTALLED_STS3215_FAMILY.stl | E:\Codex\Documents-Codex\roboto-lite-infra-portfolio\roboto_xw\reference\zeroth01\generated\solidworks\physical_mount_v1\parts\servos\S14_INSTALLED_STS3215_FAMILY_REFERENCE_LEFT_KNEE_PITCH.SLDPRT | reuse_existing_interactive_stl_surface_part | 0 | 0.0452227583155036 | 0.024722576141357422 | 0.03739971995837019 | 2159740 | 1.2443554401397705 | PASS | PASS | servo |  | S14 | left_knee_pitch | 3215_BothFlange_13
E:\Codex\Documents-Codex\roboto-lite-infra-portfolio\roboto_xw\reference\zeroth01\generated\cad\physical_mount_v1\servos\S15_right_ankle_pitch_INSTALLED_STS3215_FAMILY.stl | E:\Codex\Documents-Codex\roboto-lite-infra-portfolio\roboto_xw\reference\zeroth01\generated\solidworks\physical_mount_v1\parts\servos\S15_INSTALLED_STS3215_FAMILY_REFERENCE_RIGHT_ANKLE_PITCH.SLDPRT | reuse_existing_interactive_stl_surface_part | 0 | 0.04522275924682617 | 0.024722578935325146 | 0.03739972151538584 | 2302673 | 1.1478185653686523 | PASS | PASS | servo |  | S15 | right_ankle_pitch | 3215_BothFlange_14
E:\Codex\Documents-Codex\roboto-lite-infra-portfolio\roboto_xw\reference\zeroth01\generated\cad\physical_mount_v1\servos\S16_left_ankle_pitch_INSTALLED_STS3215_FAMILY.stl | E:\Codex\Documents-Codex\roboto-lite-infra-portfolio\roboto_xw\reference\zeroth01\generated\solidworks\physical_mount_v1\parts\servos\S16_INSTALLED_STS3215_FAMILY_REFERENCE_LEFT_ANKLE_PITCH.SLDPRT | reuse_existing_interactive_stl_surface_part | 0 | 0.04522275924682617 | 0.024722578935325146 | 0.03739972117182333 | 2305228 | 1.1629884243011475 | PASS | PASS | servo |  | S16 | left_ankle_pitch | 3215_BothFlange_13

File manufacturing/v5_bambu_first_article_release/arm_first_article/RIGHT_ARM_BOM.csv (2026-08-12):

category | item | quantity | specification | stage | source_or_link | notes
PRINT | PA6-CF filament | 1 spool | 1 kg dry spool | RA01-RA03 | https://bambulab.cn/zh-cn/filament-guide | Buy one spool for calibration and first-article failures; generated release JSON contains the current mass upper bound
PRINT | hardened steel nozzle | 1 | 0.6 mm | RA01-RA03 | https://bambulab.cn/zh-cn/x2d/specs | Use X2D main nozzle or P2S hardened nozzle
ACTUATOR | FEETECH STS3250 | 3 | ST-3250-C001 12 V TTL dual-shaft | assembly | https://www.feetechrc.com/en/562636.html | S03 right shoulder yaw; S01 right shoulder pitch; S09 right elbow yaw
TORQUE_PATH | PCD14 output bridge | 3 | 6061-T6 OD19.95 ID6.2 4x3.2 on PCD14 t2.05 mm | powered test | ../fit_check_only/04_sts3250_pcd14_output_bridge_2p05mm.step | FDM version is fit-check only
TORQUE_PATH | parent thrust ring | 3 | POM or 6061-T6 OD25 ID20.4 t2 mm | powered test | ../fit_check_only/02_sts3250_parent_thrust_ring_2mm.step | FDM version is fit-check only
FASTENER | PCD14 clamp screws | 12 | M3 metric socket head; buy M3x6/M3x8/M3x10 assortment | dry fit then power test |  | Freeze length only after measuring actual stack and thread engagement
FASTENER | centre spline screws | 3 | M3x6 | powered test |  | One per STS3250 output
FASTENER | servo case screws | 12 | M2 metric socket head; buy M2x6/M2x8/M2x10 assortment | dry fit |  | Freeze length after real servo and carrier measurement
ELECTRICAL | TTL serial-bus adapter | 1 | FEETECH-compatible half-duplex TTL with external power injection | communications |  | Do not power three servos from USB
ELECTRICAL | current-limited bench supply | 1 | 12 V >=5 A with adjustable current limit | powered test |  | Use 0.8 A / 1.2 A / 3.0 A staged limits
ELECTRICAL | inline fuse | 1 | 5 A | powered test |  | Place near supply output
ELECTRICAL | physical emergency cut-off | 1 | latching switch or accessible supply cut-off | powered test |  | Operator must reach it without touching the arm
ELECTRICAL | servo leads | 3 | FEETECH TTL daisy-chain leads | assembly |  | Route with service loops outside shear planes
ANCHOR | real torso or rigid metal bench anchor | 1 | RA00 torso OR 3 mm+ 6061 angle/plate fixed to bench | powered test |  | S03 housing must not be hand-held or fixed by cosmetic shell

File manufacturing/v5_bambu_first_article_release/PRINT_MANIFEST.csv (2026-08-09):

release_name | quantity | role | part_class | material | nozzle_mm | nozzle | layer_mm | walls | top_bottom_layers | infill_percent | infill_pattern | support | bbox_mm | solid_volume_mm3 | solid_material_upper_bound_g_each | assembly_frame_step | print_oriented_step | stl | three_mf
01_head_front_5mm_each_side | 1 | printable_head_front_shell | COSMETIC | PETG-HF white | 0.4 | standard or hardened steel | 0.2 | 4 | 5 | 25 | gyroid | paint only where overhang exceeds 50 deg; keep servo pockets and bearing faces support-free | [90.75, 70.409, 15.5] | 18986.944 | 24.113 | manufacturing/v5_bambu_first_article_release/step/assembly_frame/01_head_front_5mm_each_side.step | manufacturing/v5_bambu_first_article_release/step/print_oriented/01_head_front_5mm_each_side.step | manufacturing/v5_bambu_first_article_release/stl/01_head_front_5mm_each_side.stl | manufacturing/v5_bambu_first_article_release/3mf/01_head_front_5mm_each_side.3mf
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

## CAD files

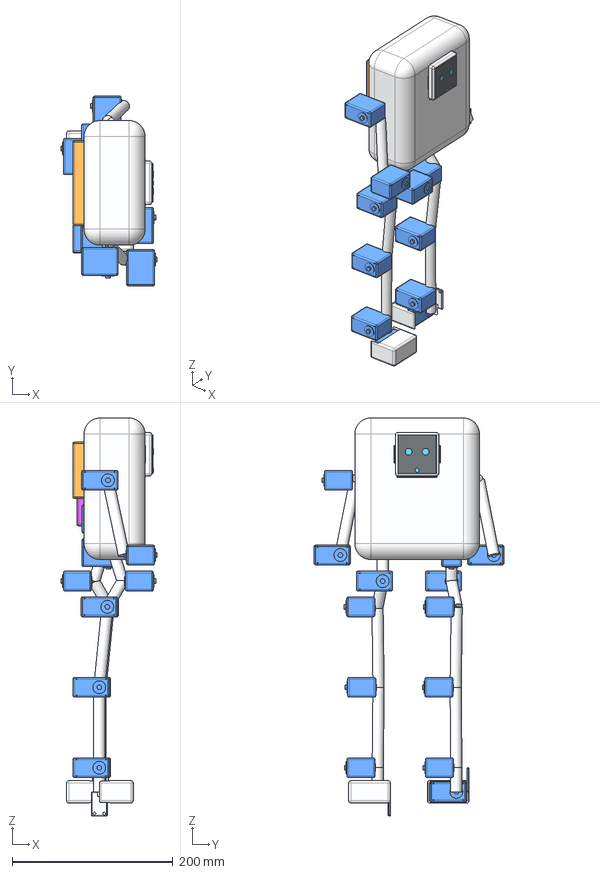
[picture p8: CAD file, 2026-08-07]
generated/cad/physical_mount_v3_rl_fixed/ZEROTH01_V3_RL_FIXED_18DOF_DIAGNOSTIC_ASSEMBLY.step
119.9 x 236.1 x 494.8 mm
V3_LIGHTWEIGHT_TORSO_ENVELOPE
DIAGNOSTIC_AXIS_LINK_Z_BOT2_MASTER_BODY_SKELETON_TO_Z_BOT2_MASTER_ SHOULDER2
DIAGNOSTIC_AXIS_LINK_Z_BOT2_MASTER_BODY_SKELETON_TO_Z_BOT2_MASTER_ SHOULDER2_2
DIAGNOSTIC_AXIS_LINK_Z_BOT2_MASTER_SHOULDER2_TO_3215_1Flange
DIAGNOSTIC_AXIS_LINK_Z_BOT2_MASTER_SHOULDER2_2_TO_3215_1Flange_2
DIAGNOSTIC_AXIS_LINK_3215_1Flange_TO_R_ARM_MIRROR_1
DIAGNOSTIC_AXIS_LINK_3215_1Flange_2_TO_L_ARM_MIRROR_1
DIAGNOSTIC_AXIS_LINK_Z_BOT2_MASTER_BODY_SKELETON_TO_U_HIP_L
DIAGNOSTIC_AXIS_LINK_Z_BOT2_MASTER_BODY_SKELETON_TO_U_HIP_R
DIAGNOSTIC_AXIS_LINK_U_HIP_L_TO_3215_BothFlange_5
DIAGNOSTIC_AXIS_LINK_U_HIP_R_TO_3215_BothFlange_6
DIAGNOSTIC_AXIS_LINK_3215_BothFlange_5_TO_3215_BothFlange_9
DIAGNOSTIC_AXIS_LINK_3215_BothFlange_6_TO_3215_BothFlange_10
DIAGNOSTIC_AXIS_LINK_3215_BothFlange_9_TO_3215_BothFlange_13
DIAGNOSTIC_AXIS_LINK_3215_BothFlange_10_TO_3215_BothFlange_14
DIAGNOSTIC_AXIS_LINK_3215_BothFlange_13_TO_left_ankle_roll_carrier
DIAGNOSTIC_AXIS_LINK_3215_BothFlange_14_TO_right_ankle_roll_carrier
DIAGNOSTIC_AXIS_LINK_left_ankle_roll_carrier_TO_FOOT
DIAGNOSTIC_AXIS_LINK_right_ankle_roll_carrier_TO_FOOT_2
S17_STS3250_right_ankle_roll x 18
LEFT_ANKLE_ROLL_CARRIER_INSTALLED
RIGHT_ANKLE_ROLL_CARRIER_INSTALLED
COMPUTE_CONTROLLED_INSTALL_ENVELOPE
BATTERY_CONTROLLED_INSTALL_ENVELOPE
IMU_CONTROLLED_INSTALL_ENVELOPE
CORES3_INTERNAL_TORSO_CRADLE_INSTALLED
PURCHASED_M5STACK_CORES3_K128_HEAD_INSTALLED
CORES3_2INCH_TOUCH_FACE_GLASS
CORES3_GC0308_CAMERA_WINDOW
CORES3_SCREEN_EXPRESSION_EYE x 2

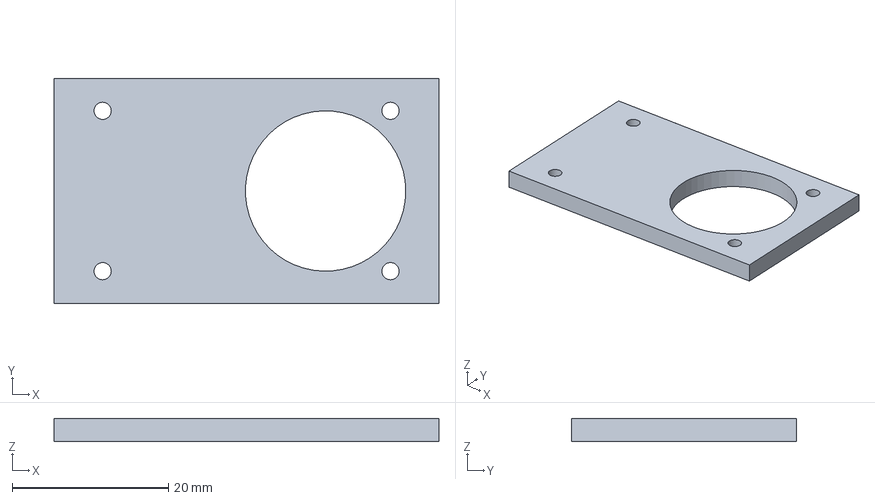
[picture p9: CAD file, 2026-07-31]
generated/cad/physical_mount_v1/sts3250_interface/STS3250_4XM2_FIRST_ARTICLE_FACE_GAUGE.step
49.2 x 28.7 x 3.00 mm

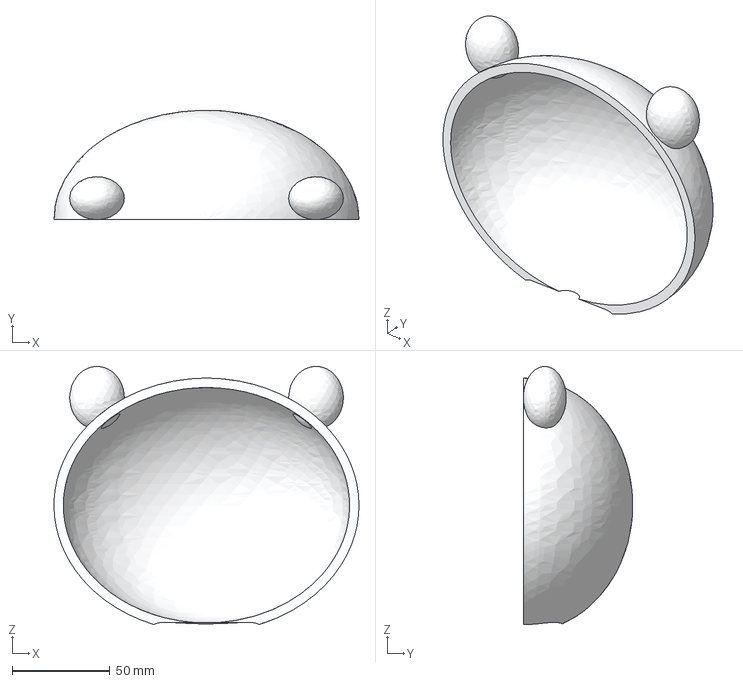
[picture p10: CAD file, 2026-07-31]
generated/cad/physical_mount_v2_minimal/parts/head_back.step
156.0 x 56.0 x 132.0 mm

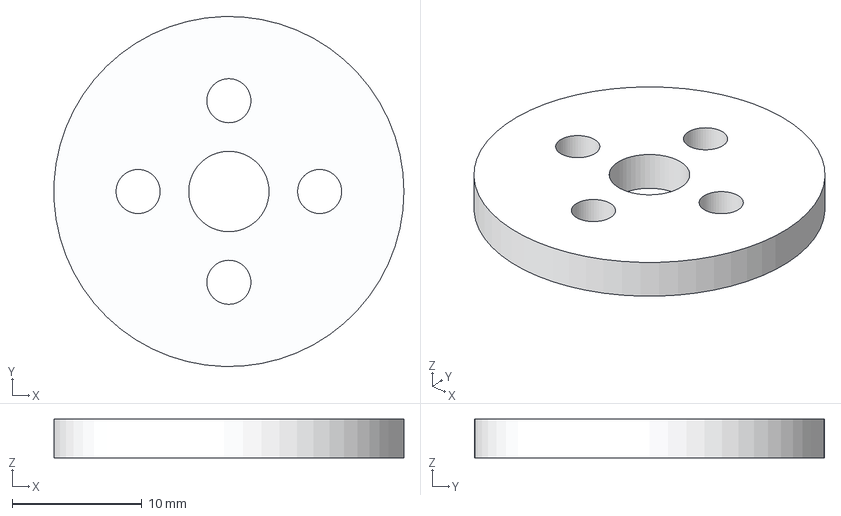
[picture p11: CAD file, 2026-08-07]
generated/cad/physical_mount_v3_rl_fixed/parts/left_ankle_roll_horn_adapter.step
27.0 x 27.0 x 3.00 mm

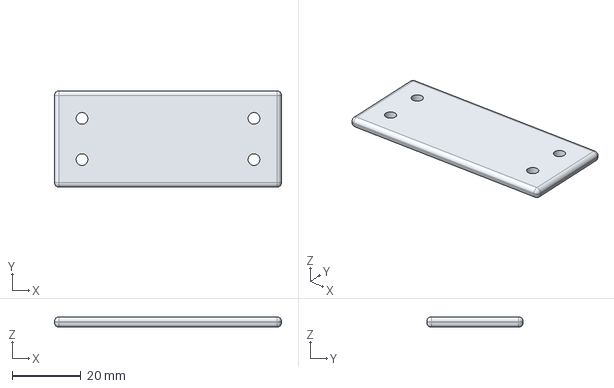
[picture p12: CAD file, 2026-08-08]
generated/cad/physical_mount_v4_original_minimal/parts/head_mount_4xm3_drill_jig.step
66.0 x 28.0 x 3.00 mm

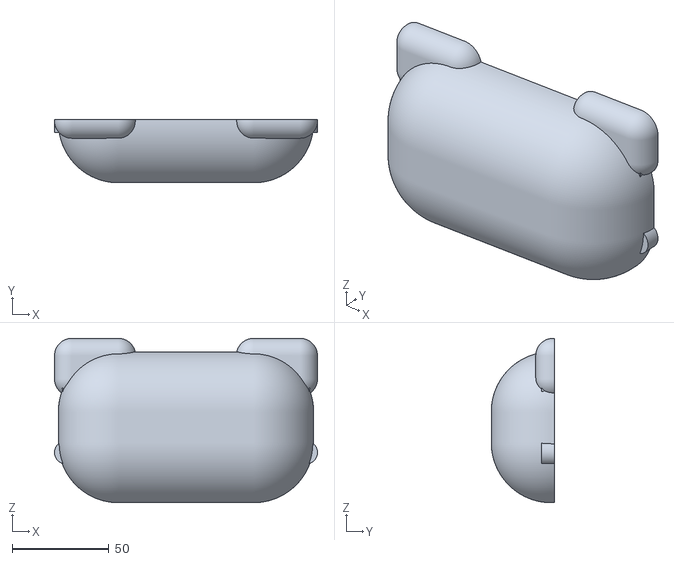
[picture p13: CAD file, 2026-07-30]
generated/print/round_v1/final/ZEROTH01_ROUND_V1_HEAD_FRONT.stl
136.0 x 32.8 x 85.0

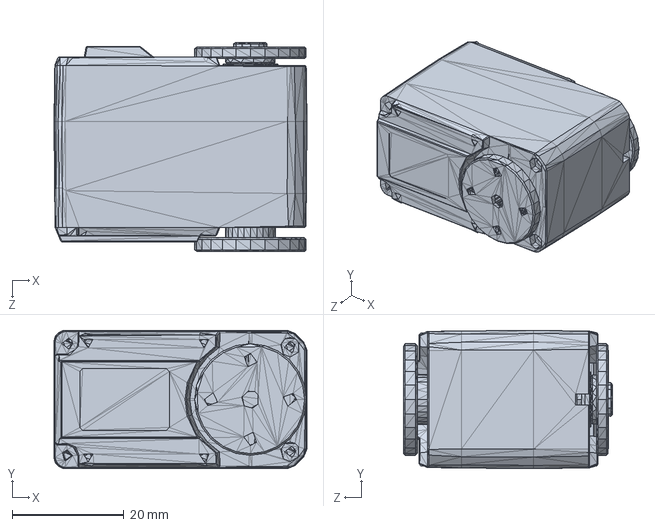
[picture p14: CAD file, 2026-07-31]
generated/solidworks/physical_mount_v2_minimal/portable_flat/S15_INSTALLED_STS3215_FAMILY_REFERENCE_RIGHT_ANKLE_PITCH.SLDPRT
45.2 x 24.7 x 37.4 mm

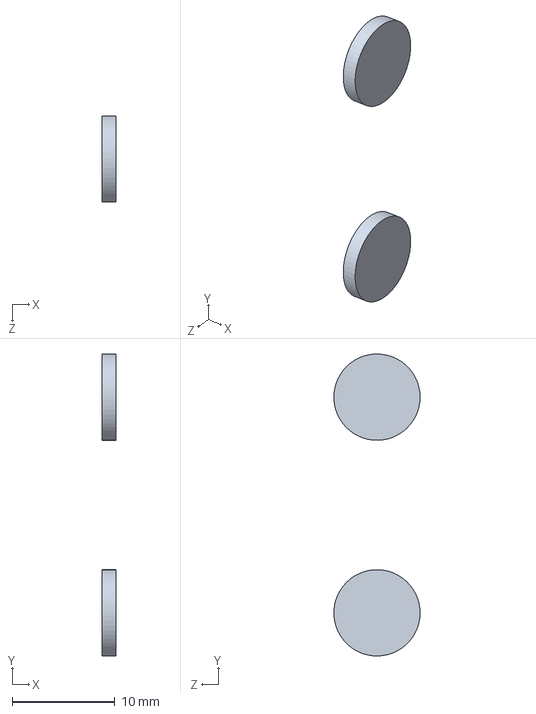
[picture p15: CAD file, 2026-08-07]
generated/solidworks/physical_mount_v3_rl_fixed/portable_flat/ZEROTH01_V3_M5STACK_CORES3_EXPRESSION_REFERENCE.SLDPRT
1.40 x 29.4 x 8.39 mm

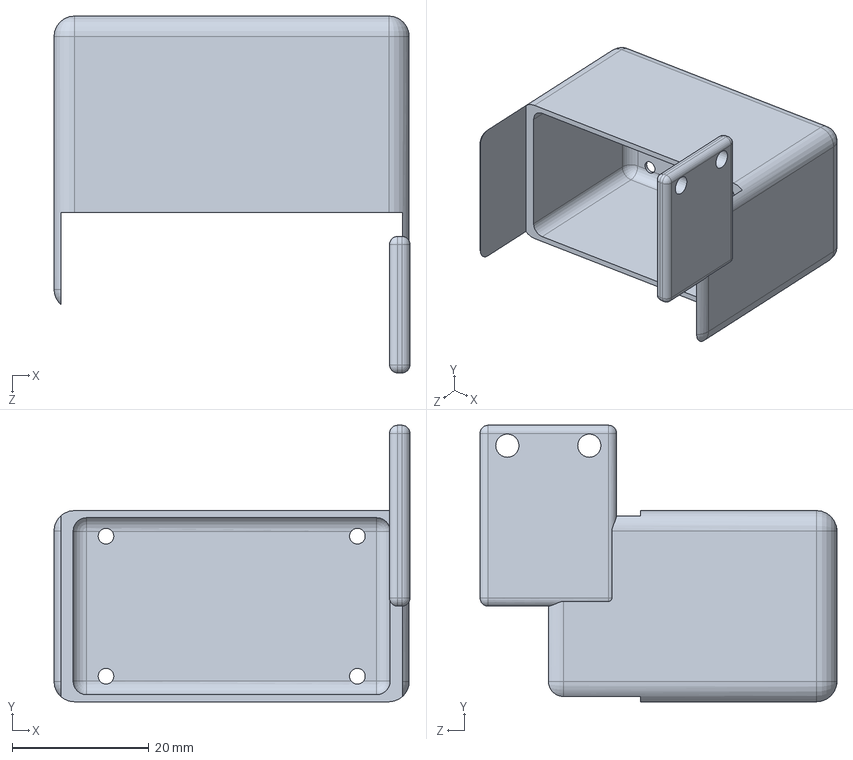
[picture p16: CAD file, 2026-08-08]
generated/solidworks/physical_mount_v4_original_minimal/portable_flat/ZEROTH01_V4_LEFT_DIRECT_ANKLE_CARRIER_26P5MM.SLDPRT
52.1 x 40.5 x 52.2 mm

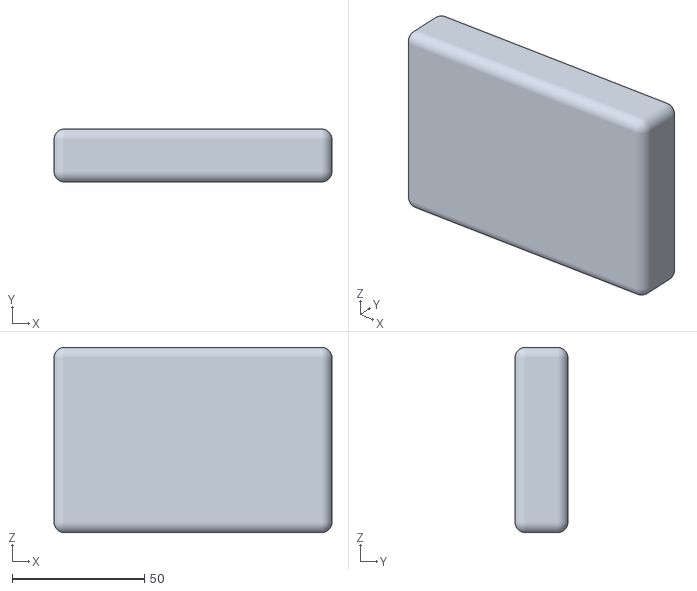
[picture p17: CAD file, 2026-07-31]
generated/urdf/physical_mount_v2_minimal/meshes/minimal/compute_module.stl
105.0 x 20.0 x 70.0

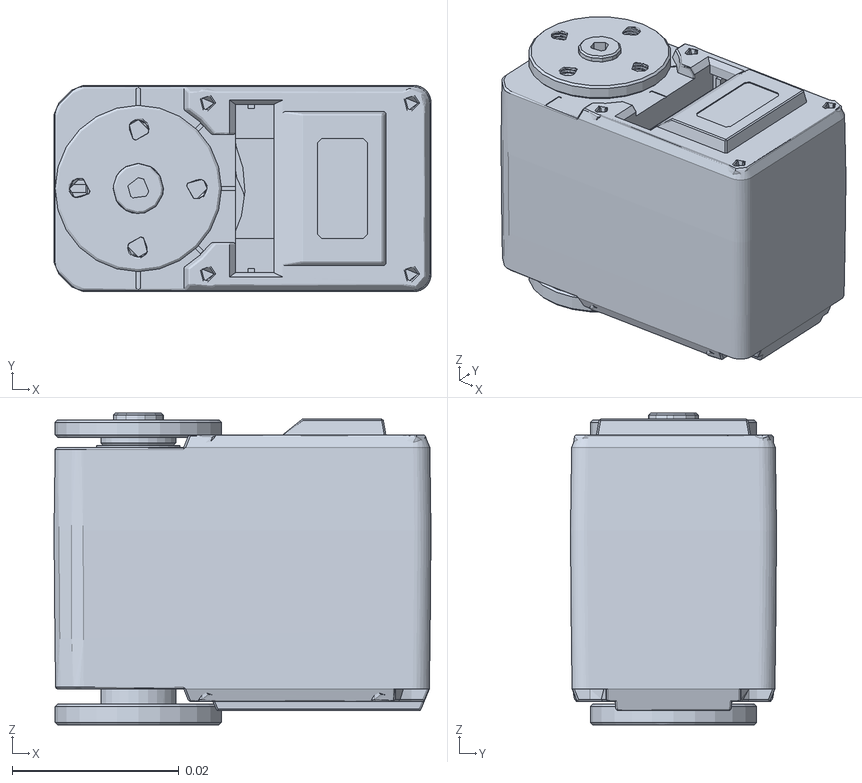
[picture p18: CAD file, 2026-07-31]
generated/urdf/physical_mount_v2_minimal/meshes/servos/S12_left_hip_roll_INSTALLED_STS3215_FAMILY.stl
0.0452 x 0.0247 x 0.0374

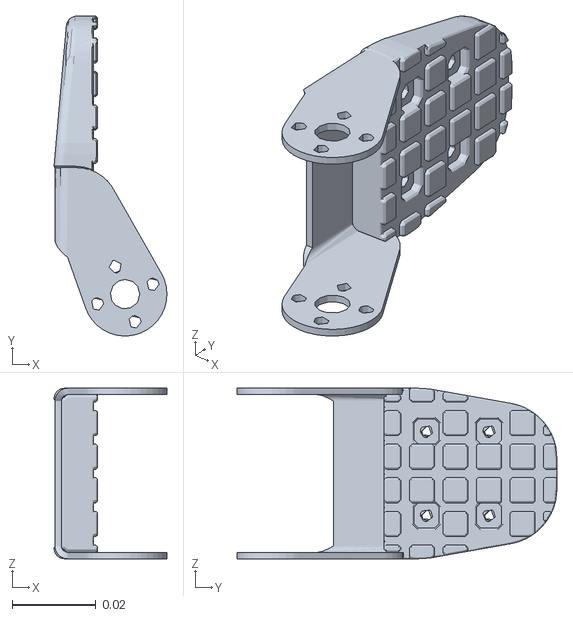
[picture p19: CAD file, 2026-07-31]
generated/urdf/physical_mount_v2_minimal/meshes/skeleton/FINGER_1_2.stl
0.0269 x 0.0763 x 0.0406

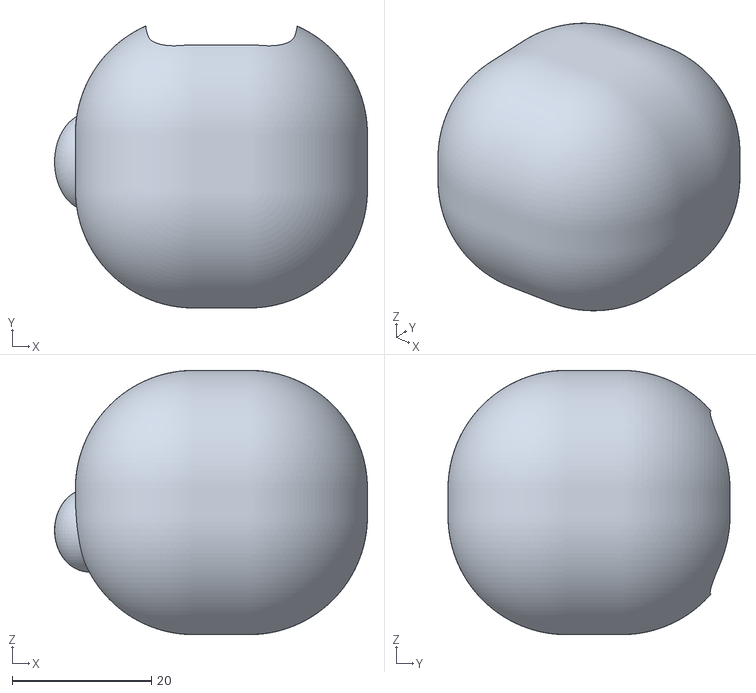
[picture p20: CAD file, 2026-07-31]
generated/urdf/physical_mount_v3_rl_fixed/meshes/minimal/left_q_hand.stl
45.0 x 40.5 x 38.0

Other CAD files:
manufacturing/v5_bambu_first_article_release/arm_first_article/RIGHT_ARM_NEUTRAL_ASSEMBLY_REFERENCE.step
cad/physical_mount_v5_original_16dof_solidworks_motion/vendor_parts/feetech_sts3250.step
generated/cad/physical_mount_v5_original_16dof_solidworks_motion/motion_link_parts/ZEROTH01_V5_MOTION_LINK_Z_BOT2_MASTER_BODY_SKELETON.step
generated/cad/physical_mount_v5_original_16dof_solidworks_motion/parts/battery_envelope.step
generated/print/physical_mount_v1/first_article/STS3250_4XM2_FIRST_ARTICLE_FACE_GAUGE.stl
generated/cad/physical_mount_v1/sts3250_interface/FEETECH_STS3250_C001_DIMENSION_REFERENCE.step
generated/cad/physical_mount_v2_minimal/parts/battery_pack.step
generated/cad/physical_mount_v2_minimal/parts/battery_pack.stl
generated/cad/physical_mount_v2_minimal/parts/camera_bracket.step
generated/cad/physical_mount_v2_minimal/parts/camera_bracket.stl
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

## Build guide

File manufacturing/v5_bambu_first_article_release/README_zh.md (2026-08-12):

# Zeroth-01 v5 拓竹首件打印发布包

## 发布边界

- 状态：`FIRST_ARTICLE_PRINT_RELEASE`。
- 目标：Bambu Studio；成形空间至少 `256 × 256 × 256 mm`。适用于 P1S、X1C、A1、H2 等同级平台；**尚未针对 A1 mini 的 180 mm 平台排版验证**。
- 主打印格式：`3mf/`。每个零件的多个闭合实体会在 3MF 中独立保存。
- 可编辑母版：`step/assembly_frame/`；已摆正到打印平台的 STEP 位于 `step/print_oriented/`。
- `stl/` 只是兼容导出。`11_3215_bothflange_10...` 和 `26_torso_mounted_solid` 的多个接触实体在合并 STL 中可能显示接触边；Bambu Studio 应使用对应 3MF。
- 不包含机器专用 G-code，因为打印机型号、喷嘴、热床板、材料批次和流量标定尚未冻结。在 Bambu Studio 中选定实际机器后切片。
- 当前 CAD 静态中立位精确 B-Rep 检查为 0 个正体积干涉；打印网格门禁为 PASS。动力运动仍是 `HOLD_UNTIL_PRINTED_FIRST_ARTICLE_DRY_FIT_AND_ISOLATED_JOINT_SWEEP`。
- 当前 16×STS3250 版本只冻结为站立/步行首件。`bug.md` 已证明现有跑步策略的膝关节 p95 速度约 5.0 rad/s，超过 STS3250 声明的 3 rad/s；不得把本包宣传为可实机跑步版本。

## 文件入口

- 打印件清单：`PRINT_MANIFEST.csv`
- 发布机读清单：`PRINT_RELEASE.json`
- 网格门禁：`validation/mesh_gate.json`
- 采购清单：`PURCHASE_BOM.csv`
- 文件校验：`SHA256SUMS.csv`
- 全部打印件诊断母版：`ZEROTH01_V5_BAMBU_PRINTABLE_PARTS_DIAGNOSTIC.step`
- 4 个舵机接口样件：`fit_check_only/`
- 右臂优先首件、X2D/P2S 工艺差异与低电流台架流程：`arm_first_article/`

## 推荐打印参数

### 承力件（PA6-CF）

- 文件：清单中 `part_class=STRUCTURAL` 的 22 件。
- 喷嘴：0.6 mm 淬硬钢；层高 0.20 mm。
- 壁数：5；顶/底：6 层；填充：45% Gyroid。
- 打印前按材料厂家要求彻底干燥；打印过程中保持干燥供料。
- 仅在超过 50° 且确有需要的位置手绘支撑。舵机槽、轴承/推力面、螺钉贴合面和 PCD14 接口面尽量不生成支撑。
- 首层完成后检查翘边；结构件不得用 PLA 替代。

PA6-CF 通常为黑色。整机要白色时，先完成装配与运动首件，再对外露结构件使用尼龙兼容底漆和白色面漆。白色 PA6-GF 虽可采购，但层间冲击指标与 PA6-CF 不同，不能未经同批试样拉伸/冲击和关节疲劳验证直接替换承力材料。

### 外观和维护件（PETG-HF）

- 白色：头部前壳、后壳；黑色：面罩；其余服务托架颜色不限。
- 喷嘴：0.4 mm；层高 0.20 mm；4 壁；顶/底 5 层；25–30% Gyroid。
- PETG 也必须干燥。头壳装配孔和摄像头开口先用去毛刺刀手工清理，不要直接扩大 CAD 孔径。

## 首件顺序

1. 先打印 `fit_check_only/01_sts3250_4xm2_first_article_face_gauge.3mf`，用一只真实 STS3250 验证 4×M2 后盖孔、输出轴位置和壳体外形。
2. 打印一套最典型关节：一个腿部承力架、一个肩部承力架、一个脚部件和 PCD14 塑料样件。塑料 PCD14 桥/环仅用于配合检查，不能进入动力扭矩链。
3. 记录实际孔径、轴心偏差、装配间隙、螺钉有效啮合长度和材料收缩；若需要补偿，只修改源 STEP/Python 后重新生成全包。
4. 样件通过后打印 torso、左右腿、左右臂和内部托架；头壳最后打印。
5. 去毛刺、热熔螺母安装和无舵机干装后，再装 1 个舵机做单关节限位慢扫；每次只使能一个关节。
6. 16 个关节全部完成实体零位、方向、ID、背隙、线束余量和机械硬挡检查后，才允许低扭矩站立测试。

## 质量和耗材

- 30 个打印源件的“按完全实心体积计算”材料上限约 `702.6 g`：PA6-CF 约 `602.2 g`，PETG-HF 约 `100.4 g`。这不是切片质量；45%/25–30% 填充后的实际用量通常更低，但支撑、裙边、流量标定和失败余量会增加耗材。
- 采购建议：PA6-CF 1 kg、白色 PETG-HF 1 kg、黑色 PETG-HF 0.25–1 kg。正式开打前以 Bambu Studio 的实际切片统计复核。
- 当前 URDF/MJCF 标称整机质量为 `2.745759 kg`。打印后必须逐 link 称重、测 COM/惯量并做 SysID，再覆盖 RL 惯性；不能把 CAD 材料上限直接写回 URDF。

## 不可打印成最终承力件的接口

`fit_check_only/02`、`03`、`04` 只用于塑料配合试装：

- 输出桥：OD 19.95 / ID 6.2 / 4×Ø3.2 on PCD14 / 厚 2.05 mm，最终建议 6061-T6 CNC 或精密板件。
- 父侧推力环：OD 25 / ID 20.4 / 厚 2 mm，最终建议 POM 或 6061-T6 精密加工。
- 髋 yaw 四套筒：OD 4 / ID 3 / 长 1.65 mm，最终使用金属精密套筒或研磨定厚件。

最终金属件以该目录 STEP 询价。未经实测，不允许用 FDM 塑料件承受 STS3250 的动力输出扭矩。

## 上电前硬门禁

- 逐关节手动全行程无卡滞，静态和运动间隙均可见；线束不经过剪切面。
- 所有输出桥、套筒、锁紧螺母和保险丝为最终件；舵机壳体固定与输出侧明确分属父/子 link。
- 3S 电池尺寸不超过 `75 × 22 × 34 mm`，极性和 XT30 插头核对；主电源有保险丝和物理急停。
- 先用限流电源和单舵机，再用双腿台架，最后才装电池整机上电。
- 当前 Z4/L3 跑步 checkpoint 禁止上机；保留 STS3250 时需重训硬件限速步行策略。

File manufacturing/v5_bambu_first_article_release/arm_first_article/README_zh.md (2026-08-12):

# Zeroth-01 V5 右臂首件包

## 结论

- X2D 与 P2S 使用**同一套 STEP/3MF**，不能为了打印机型号分叉机器人 CAD。
- 两台机器的切片、支撑、热收缩和孔补偿不是同一制造工艺，因此最终实物尺寸不保证天然相同；每台机器、每批 PA6-CF 都必须先通过 `FC01` 配合样件。
- 本包先冻结一条右臂的承力链：3 个必打件、3 个 STS3250、3 组金属输出接口。数字子装配已从 V5 occurrence manifest 提取；实体上电仍保持 `HOLD`，直到 `RIGHT_ARM_POWER_TEST_CHECKLIST.csv` 的 G00–G09 全部实测 PASS。

## 文件入口

- 打印件：`required_arm/3mf/`
- 可选、暂不上电的腕端支撑：`optional_unpowered_wrist_support/3mf/`
- 可选真实机身固定端：`optional_real_torso_anchor/3mf/`
- 配合样件：`fit_check_only/`
- 打印清单：`RIGHT_ARM_PRINT_MANIFEST.csv`
- 三关节真实力矩链：`RIGHT_ARM_TORQUE_CHAIN.csv`
- 彩色数字子装配：`RIGHT_ARM_NEUTRAL_ASSEMBLY_REFERENCE.step` / `.glb`
- 采购与工装：`RIGHT_ARM_BOM.csv`
- 低电流上电流程：`RIGHT_ARM_POWER_TEST_zh.md`
- 打印机差异：`PRINTER_COMPATIBILITY_X2D_P2S.md`

## RA 编号

| 编号 | 颜色 | 实际用途 | V5 link / 特别说明 |
|---|---|---|---|
| RA01 | 黄 | 右肩双轴转接架 | `Z_BOT2_MASTER_SHOULDER2_2` |
| RA02 | 橙 | 右上臂承力架 | `3215_1Flange_2`；承载 S01、S09 舵机壳体 |
| RA03 | 绿 | 右前臂/腕端承力架 | `L_ARM_MIRROR_1`；这是上游镜像命名，实物侧是**右臂** |
| RA04 | 青 | 可选右腕圆角支撑 | 当前两颗长 M3 的跨距/啮合尚未冻结，已从首轮动力链和装配参考中剔除 |
| RA00 | 灰 | 可选真实机身固定端 | 只有采用整块真实 torso 固定 S03 时才打印；台架也可用刚性金属固定端替代 |
| 舵机 | 蓝 | 3×购买件 STS3250 | S03 肩 yaw、S01 肩 pitch、S09 肘 yaw |

3 个必打件按完全实心体积计算的 PA6-CF 上限约 `45.940 g`；这不是 Bambu Studio 切片重量。

## 推荐首件顺序

1. 用廉价 PETG 打 `FC01`，拿真实 STS3250 检查 45.22 × 24.72 mm 壳体基准、4×M2 和输出轴中心。记录实际偏差，不要直接锉大正式件。
2. 只打 RA01–RA03。RA04 暂不打印、不参与上电。正式承力首件使用干燥 PA6-CF、0.6 mm 淬硬钢喷嘴、0.20 mm 层高、5 壁、6 层顶底、45% Gyroid。
3. 打印的 FC02/FC03 仅做配合；上电前更换为 6061-T6/POM 最终件。FDM 塑料输出桥不得进入动力扭矩链。
4. 无电干装三关节。确认 S01 是合法的反装结构：输出桥固定在 RA01，而舵机壳体随 RA02 运动；不要把 S01 壳体强行固定到 RA01。
5. S03 的壳体必须固定在真实 torso 或刚性金属台架上，整条手臂不能手持、悬空上电。
6. 执行 `RIGHT_ARM_POWER_TEST_zh.md`；通过后才镜像推进左臂和整机打印。

## 当前证据边界

- 已有：V5 精确购买件 STS3250 STEP、静态 B-Rep、URDF/MJCF、三关节父/子 link 和彩色子装配。
- 尚无：你手中这批舵机、喷丝批次、孔补偿、金属件、螺钉啮合、线束和真实载荷的实测结果。
- 当前 manifest 中三只右臂舵机的 6D 拟合残差为约 2.611–3.149 mm；清空后的 B-Rep 名义正体积干涉为 0，但这不是实际 M2 孔/壳体固定强度的签字数据，正是 FC01 与右臂首件必须先做的原因。
- 首轮可视化发现 RA04 依赖未冻结的长通孔螺栓且在无紧固件模型中表现为悬空；它已被降级为可选研究件，避免把非承力外观件误当成可上电连接。
- 所以现在可以开打右臂首件并做受控台架测试，但不能在打印前宣称“实物必然直接装上并可满扭矩运行”。

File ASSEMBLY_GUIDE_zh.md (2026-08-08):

# Zeroth-01 v5 原始 16DoF 首件装配指南

本指南用于制造验证，不代表“整套直接打印即可一次装好”。数字 B-Rep、URDF/MJCF 已通过；SOLIDWORKS 当前 manifest 的原生 Motion、采购件公差、打印强度、线束和动态负载仍为 HOLD。

## 1. 先做四类试片

1. 采购一只 FEETECH STS3250-C001，对照 `parts/sts3250_step_parts_exact_shaft_frame.step` 验证 45.22×24.72×约 36.5 mm 包络、后盖 M2 孔、25T/5.9 mm 输出和 PCD14 4×M3。
2. 打印一侧髋 yaw 躯干座、U 形髋避让区、PCD14 输出桥和 M3 套筒；以 0.20–0.35 mm 为起始工艺间隙，不把 CAD 名义零间隙当打印公差。
3. 打印一个两 M3 小腕端和左右 9 mm 脚底；验证螺钉头、工具可达和脚底接地平面。
4. 做热熔嵌件拉拔、层间剪切、重复拆装和低速堵转保护试验，再冻结 PETG/PA-CF/PC、壁厚、层向和螺钉扭矩。

## 2. 关节力矩链验收

每个 S01–S16 必须同时满足：

1. STS3250 机壳属于静止侧 carrier，不能悬在外观壳或标注线上。
2. 舵机轴线与 actuator layout 中的轴线重合，左右关节由同一账本镜像生成。
3. PCD14 四孔输出桥属于运动侧 carrier；拉动运动侧时，输出桥必须与运动侧一起转。
4. 静止侧 carrier、舵机壳体、内部齿轮/输出、PCD14 桥、运动侧 carrier 构成连续力矩链。
5. 原生 SOLIDWORKS 中只允许绕该轴转动并受上下限 mate 约束；不得用漂浮组件或动画变换伪造。

## 3. 髋 yaw 专项顺序

1. 躯干使用 `torso_mounted_solid.step`，其中左右 2×M2 窄肋/螺柱已与固定躯干融合，不另装背板。
2. 把精确 STS3250 放入左右近贴合槽位；每侧从服务侧装入 2 根 M2×8。螺钉必须穿过融合螺柱并进入采购舵机后盖孔。
3. 输出侧装 2.05 mm PCD14 桥，再用四个独立 M3 套筒闭合到 `U_HIP_*_MOUNT_CLEARANCED.step`。
4. 手动从下限慢转到上限，确认固定螺钉/肋与 U 形髋不接触；数字证据见 `hip_yaw_dynamic_mount_screen.json` 和 `hip_yaw_uhip_mount_clearance.json`。
5. 不安装整圆垫片、悬空桥板、黄色背板或额外踝舵机。

## 4. 上肢、头部与脚

- 肩、肘沿原 Zeroth carrier 顺序安装；左右支架必须镜像，舵机不能通过偏置外观件补偿。
- 腕端仅装两 M3 小型圆角支撑，不装夹爪、大球手或方块手掌。
- 头罩前后两片上下左右各扩 5 mm，以四 M3 隐藏螺母板直接连躯干，外露间隙不超过 5 mm；UnitV2 可从内部托架拆出，保留摄像头、麦克风、USB-C 和散热通道。
- 脚底白色、9 mm、上窄下宽；四 M3 通孔连接原脚。黑色鞋底和踝 roll 舵机均不存在。

## 5. 电气与线束

- 计算板最大预留 70×12×32 mm；电池最大 75×22×34 mm；IMU 最大 32×8×25 mm；UnitV2 48×18.5×24 mm。
- 这些彩色包络必须在躯干/头罩内部，不得作为外露背板。精确采购件冻结后再改托架孔位。
- 舵机总线、动力、USB 和传感线分层走线；每个活动关节留服务环和应变释放，线束不得跨剪切面。
- 逐只上电低速 jog，填写 hardware calibration CSV；候选总线 ID 不具权威性。

## 6. 放行顺序

1. 32 次原生 SOLIDWORKS 单关节上下限 Motion、静态/动态干涉 PASS。
2. 无电实物全行程和镜像检查 PASS。
3. 低压悬吊单关节、限流站立、真实线束慢扫 PASS。
4. 称量整机与各 link，摆振/阶跃/扫频 SysID，覆盖质量、COM、全惯量、摩擦、背隙、延迟和扭矩增益。
5. RL 输出峰值/RMS 扭矩、电流、温升、足底接触、跌倒和紧固件松动闭环后，才可把 `physical_first_article` 改为 PASS。

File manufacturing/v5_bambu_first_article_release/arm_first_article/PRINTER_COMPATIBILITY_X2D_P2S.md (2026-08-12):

# X2D / P2S 打印兼容矩阵

## 不变的内容

- CAD、STEP、3MF、孔位、轴线、URDF 和装配零位全部相同。
- RA01–RA03 必打件最大包围盒边长约 100.015 mm；可选 RA00 torso 最大边约 134.605 mm，均小于两台机器的 256 mm 级成形空间。RA04 暂不进入动力首件。
- 结构件统一使用 0.6 mm 淬硬钢喷嘴；不为某台打印机人工缩放 STL。

## 必须分开的内容

| 项目 | X2D | P2S |
|---|---|---|
| 官方成形空间 | 主喷嘴 256×256×260 mm | 256×256×256 mm |
| PA6-CF 热端 | 使用主热端；辅助热端官方列为谨慎打印 | 官方支持 PA6-CF |
| 热床上限 | 120 ℃ | 110 ℃ |
| 腔体 | 主动控温，最高 65 ℃ | 封闭机箱；官方参数未列主动腔温加热 |
| 本项目文件 | 同一 3MF/STEP | 同一 3MF/STEP |
| Bambu Studio | 选择 X2D、主喷嘴和实际 PA6-CF 批次 | 选择 P2S 和实际 PA6-CF 批次 |

X2D 对 PA6-CF 的工艺余量更大，但这不意味着自动得到更准确孔位；P2S 也能打印，必须加强耗材干燥、腔体热稳定和翘曲检查。两台机器各自跑 FC01，并把 XY 孔补偿、流量、收缩和批次记录在制造记录中。

## 支撑和摆放

- 使用发布包已摆正的 `print_oriented_step` 或对应 3MF。
- 舵机槽、轴线配合面、PCD14 面和螺钉贴合面禁止自动支撑侵入；仅手绘必要支撑。
- X2D 双喷嘴不是本首件的必要条件。PA6-CF 使用主热端；若未来试验异材支撑，要重新验证界面污染和尺寸，不能直接沿用当前放行。
- 不提交通用 G-code：G-code 必须绑定实际打印机、喷嘴、板材、材料批次及该机标定。

官方参数：

- [Bambu Lab X2D 技术参数](https://bambulab.cn/zh-cn/x2d/specs)
- [Bambu Lab P2S 技术参数](https://bambulab.cn/zh-cn/p2s/specs)
- [Bambu Lab 耗材指南](https://bambulab.cn/zh-cn/filament-guide)

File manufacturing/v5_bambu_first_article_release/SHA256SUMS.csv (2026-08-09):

path | bytes | sha256
.ZEROTH01_V5_BAMBU_PRINTABLE_PARTS_DIAGNOSTIC.step.glb | 39404736 | e7b9454536667be439116188b97a46766cfdc6498b70656390c1eeb5a6e2509b
3mf/01_head_front_5mm_each_side.3mf | 97586 | 1a07e624508c26f766f8377318ad92e062b8b221c71c1b55d38702bcf7e5e758
3mf/02_head_rear_5mm_each_side.3mf | 87641 | 292fdec2f7157e524436bb9b737a93b9635d978c088a3ddc5aff7baaae9d843d
3mf/03_head_simple_visor.3mf | 56117 | 928238c10f0c113fc292a2c6554b43e644c2d19b8289e9ea1d14cc56e4c47756
3mf/04_battery_service_cage.3mf | 100046 | 0d50bca3735843de7eeeb3421fa195294653ef108c90f21843dba470b1fbf010
3mf/05_compute_removable_tray.3mf | 106308 | b51e16533500ef6aa0ea473118417b6cf3eed093928128659e9e1be346aa1fbe
3mf/06_harness_strain_relief_guides.3mf | 253747 | 0bdce0d615aafd86ccf9313d1a231578060d835d429c30abb796ec323237caa1
3mf/07_torso_imu_shelf.3mf | 44368 | c4091115d61547fec56551ff6006e1d92b36f24a011165ca1741291e7b6ee6fe
3mf/08_unitv2_removable_cradle.3mf | 154473 | 86b5b804abd00b583830d7dc8afaa9b777cb23af85ed3b9f192f4abbb9145baa
3mf/09_3215_1flange_2_sts3250_clearanced.3mf | 23281 | f6f379025acf844c5108de8ec9870e35ba0e23c684c076638945eb3ffc5d2d93
3mf/10_3215_1flange_sts3250_clearanced.3mf | 23505 | 52ce1fefd214e6a359d45d6bbed22a9b53fe5829ab6d51f4bb0a29871624fc26
3mf/11_3215_bothflange_10_sts3250_clearanced.3mf | 44468 | a96ca7fb13d4d4c3df19c3c43671538cc178d6d29dc06edde86c5e7ba2864e67
3mf/12_3215_bothflange_13_sts3250_clearanced.3mf | 19351 | e5f8dfa73a7a7aaa11af80c1e704c214918bcd4febc344f0e1b0a81ac0895f24
3mf/13_3215_bothflange_14_sts3250_clearanced.3mf | 18968 | e81c5d5eeae0df0466f42722cf96b605ccd39d40ae432791d6f9b670d758e0ea
3mf/14_3215_bothflange_5_sts3250_clearanced.3mf | 19557 | 6c51d13f21ce2e4442eedc6c2cebd7afe18c8ca9fcdf20b30d7638a029063863
3mf/15_3215_bothflange_6_sts3250_clearanced.3mf | 18706 | b01b09b22deabf177963e8baa8289a876c4946f806416130aa9994d37e77200e
3mf/16_3215_bothflange_9_sts3250_clearanced.3mf | 43402 | 965ca9c95f34babb647b90b8a999379ab03a6d29779cd7640a8301001b567b37
3mf/17_direct_head_torso_nut_plate.3mf | 62310 | 2656b629b1e6082877d74bc12aba8cbd2949ff518c7bcbd08c352ad3a4000436
3mf/18_foot_2_sts3250_clearanced.3mf | 52514 | 56a72817a2ab72d984eaa0b796daa207deeebda93260ca5e27d9a927b9686706
3mf/19_foot_sts3250_clearanced.3mf | 52507 | d369e73a05acbebe83ff7ad2fa949b3b5241241efd6b83a426cfec230c29d267
3mf/20_l_arm_mirror_1_sts3250_wrist_mount.3mf | 203070 | e0cf2d854b5d6265b84f1112d17c9f324ddf55bd116151c53f35afc74a8e7832
3mf/21_left_fixed_wrist_support.3mf | 56687 | 55c9d24982441b772bb80d6ff7cec8f2a70eca8b8114e1de4621922a8616b5a5
3mf/22_left_tapered_sole_flare.3mf | 78209 | b6701408b85a2eaabbbf3b889357eccdd7d31ad7bc6a8f38864c59e820a7c35d
3mf/23_r_arm_mirror_1_sts3250_wrist_mount.3mf | 227951 | ddde4b7d78046317fc6ce8725499c720f8cc51a39ac2f48c31307f23410863c2
3mf/24_right_fixed_wrist_support.3mf | 57571 | 921c4c1f34c872d87cb224383268cd59c7857ca70eeb153faa10fabb9fc7c0f2
3mf/25_right_tapered_sole_flare.3mf | 78151 | 8bd84f87ac98d9fcadb0aeb22c326f20173565df67793477b1bad2d8ac4d4881
3mf/26_torso_mounted_solid.3mf | 337909 | dccd526f521703f5f8a0a339e2dd2c234c19ec3073952c8372ede08655661391
3mf/27_u_hip_l_mount_clearanced.3mf | 20958 | dd2d726a5047b925fd8f6e623a93c6eb7ed35fefab901bba651655f24eb3c0cb
3mf/28_u_hip_r_mount_clearanced.3mf | 17811 | 97ab9421dc2ba70ff19d38f2218c5d42cd31c78d4698b688e908f7c7e8cdb109
3mf/29_z_bot2_master_shoulder2_2_sts3250_clearanced.3mf | 17276 | 583e9c79dec9100e386f35e1286f561bc7f748bb9bd840fd8917610e8edd5ed5
3mf/30_z_bot2_master_shoulder2_sts3250_clearanced.3mf | 17954 | b11f59a56178b6c49321aef2c0ebb7b8ab26ae127d4398b926dcb7d0c9617000
fit_check_only/01_sts3250_4xm2_first_article_face_gauge.3mf | 20236 | 0304087df335e64d8b3379d7c42549508beffb0fcf17005397bc0ac5aa03900d
fit_check_only/01_sts3250_4xm2_first_article_face_gauge.step | 35417 | 485f216cae1daf3a594408444d1391f4b5bd11b0f8c5e8d71de6e09bc5be6291
fit_check_only/01_sts3250_4xm2_first_article_face_gauge.stl | 85684 | a174f02fdd79585b1aba3d32842e33b213e5d7530b2f7f69c4893124269daedd
fit_check_only/02_sts3250_parent_thrust_ring_2mm.3mf | 20418 | e601a8fbb2ead1331e7c4559fc66a74a699b6789cf11f491304b130d55d046e1
fit_check_only/02_sts3250_parent_thrust_ring_2mm.step | 43792 | 4cd4333f619c96f44aff518d8a3285292386ae9b7a256de65e2bef008de0eedf
fit_check_only/02_sts3250_parent_thrust_ring_2mm.stl | 92084 | 7120ef5452e6145ab80b5ace5b9ec6f726dbcaddd98ee41e6a15ad3dc9b60f6b
fit_check_only/03_sts3250_pcd14_four_sleeve_spacer_1p65mm_z0p30.3mf | 26645 | 5ab4ed2a041252afb593094715c3357a31a4ac809cb8ac7cc32d3ce84dd83441
fit_check_only/03_sts3250_pcd14_four_sleeve_spacer_1p65mm_z0p30.step | 38933 | c3186c19d5f88e138f71c3ab77455ac3763e7ffb9737e316c603e252edc5ddb8
fit_check_only/03_sts3250_pcd14_four_sleeve_spacer_1p65mm_z0p30.stl | 134484 | c72b402875b961d0a5229ce53319aace17b1d426efd600ec2e9aa9b91df1d4cf
fit_check_only/04_sts3250_pcd14_output_bridge_2p05mm.3mf | 22466 | 231ce1fc70181b68cbe4d2b3c15abb58f54a63575b1cd7ed06bba83bc6477982
fit_check_only/04_sts3250_pcd14_output_bridge_2p05mm.step | 25738 | 9637ab71dddc7098b11a730b2c64cf09fbd6bf553f794c553b958b60a21489c9
fit_check_only/04_sts3250_pcd14_output_bridge_2p05mm.stl | 101684 | fd178693de50ae45ffbcd81424dac1570f7b075d86674ffe49a2b411d1d788e2
PRINT_MANIFEST.csv | 19138 | 03460b146865d2aff2d95a4710cf185286b10d7dc34bfb5021cdcfebbcbc9db1
PRINT_RELEASE.json | 49156 | 7cbab8fd108518a1a286fd3121b79aaab85478cf802b35027310bc273c3729a3
PURCHASE_BOM.csv | 9758 | baa8fc231c699f69786c29ce26390ce20f7ed6dc721e45fa762bb7a178abcfea
README_zh.md | 5375 | ffdeb96f7f61b0c8a162a1717d13c5be4d91407e55c6cc72c9512ff9b9485660
step/assembly_frame/01_head_front_5mm_each_side.step | 231577 | a5ad0e0403887378e492c55550f952254a811a810e17e5d6e363ea221d624989
step/assembly_frame/02_head_rear_5mm_each_side.step | 257993 | 582ffa97978457fb7912275890c6ffc97043e1b9dfc187460b05f6327d809cc3
step/assembly_frame/03_head_simple_visor.step | 75540 | 6325420bb3d8cef800013ff4bdefe07621cb258176127451f9b0f913464429f3
step/assembly_frame/04_battery_service_cage.step | 247214 | 1c02697658093af340c62e2a580d896ef3c62afc8885802a90ef520c78fcdfa2
step/assembly_frame/05_compute_removable_tray.step | 255856 | 6ab8af61ee2ab6877eb443412e00ceb72a09d241af269e3dbaef121524aa4df0
step/assembly_frame/06_harness_strain_relief_guides.step | 658715 | 91dacdf307df9a3e96e7d098d259e6c2682a55f52a5bd93a5d8d04bfc546ca2e
step/assembly_frame/07_torso_imu_shelf.step | 66865 | 2a6e047e3f3e3678dfbaf38c0fec390dbb4b9e06b97be0fa26e0f0d3cbfd9c0c
step/assembly_frame/08_unitv2_removable_cradle.step | 306602 | 0f51c58e283b3a7e32122d9d9d90232b832fbefffb8c69448a800c229365db78
step/assembly_frame/09_3215_1flange_2_sts3250_clearanced.step | 1995415 | 7e01d948ada19474141c1daf4d30ea514c03d9add34d777d702d1ed96781daee
step/assembly_frame/10_3215_1flange_sts3250_clearanced.step | 2025247 | 681a0a9307480bd93a4f52db1d702c6e488901da549b787f19243fa2cf9b5106
step/assembly_frame/11_3215_bothflange_10_sts3250_clearanced.step | 4644724 | 60615afb0b24fd89b9e5fe9e5e8349178f751ae030dae9216520b0a6588164a6
step/assembly_frame/12_3215_bothflange_13_sts3250_clearanced.step | 1645244 | 93e3dcdfedabc8af64c2ecda924e2cb81f027fdc5f90ac2fe6ea00baf704405c
step/assembly_frame/13_3215_bothflange_14_sts3250_clearanced.step | 1638788 | a14c47afa1d2ef75495ff2fc40fb685b5e0f8bf6700a47db5deb384ad287a2a8
step/assembly_frame/14_3215_bothflange_5_sts3250_clearanced.step | 1762697 | c572627fd59de801e49d8512428c02ed2b63a7541d6f0f143a17bc005c86d8a2
step/assembly_frame/15_3215_bothflange_6_sts3250_clearanced.step | 1707674 | 163e328e1ed5477120ff6d634828e0222b3b25f1776a570fb24b555a3fab212c
step/assembly_frame/16_3215_bothflange_9_sts3250_clearanced.step | 4378157 | d6ce51d707fdaf60e41f2fa8843948b34b57ea658664d4059cc3c990b6765665
step/assembly_frame/17_direct_head_torso_nut_plate.step | 80627 | acca1795da8eb516a86b16d9eca2b7113100a32609cc516cbaa580f9a9568028
step/assembly_frame/18_foot_2_sts3250_clearanced.step | 4908330 | 848113b87a31dcba2597b1c84e3ed07f5d9234b81c9c91a2d5627ed719ae8c29
step/assembly_frame/19_foot_sts3250_clearanced.step | 4908577 | 34c217b2969cae8e4b4b162e12eb3bd0d0b6ee09e534302b169dca8c82a95aad
step/assembly_frame/20_l_arm_mirror_1_sts3250_wrist_mount.step | 22630165 | bfcbc433c57394bd3d3b6f866070956debf822c17480150276c4ca6d23ffb690
step/assembly_frame/21_left_fixed_wrist_support.step | 74399 | 1c8b9e32f08ea85cb98c744de0648d1c83e4a1b34edabed561709c74e3511ae7
step/assembly_frame/22_left_tapered_sole_flare.step | 160647 | e84216836f2559a858910620b33865be5ec33716c742ea93c089b2de5e593477
step/assembly_frame/23_r_arm_mirror_1_sts3250_wrist_mount.step | 17531809 | 3c5de511edf3a6c84c035d26dd1aafb208c2f7a21285fd39b8d07037c855033f
step/assembly_frame/24_right_fixed_wrist_support.step | 74290 | a82026e775b8ad6deee3a37a85d7db092d1b715af12a5f1592185e471195127b
step/assembly_frame/25_right_tapered_sole_flare.step | 165806 | 41abd58284fd800e903b08bc7b6ad1e5ec8d29f73ad4b018a042d24f6ae9e0ad
step/assembly_frame/26_torso_mounted_solid.step | 10264214 | b3b0862f386d30cd89a4f0a6ed0ba31580f014ea8a6c8e8e303d925419091f94
step/assembly_frame/27_u_hip_l_mount_clearanced.step | 2236054 | 904c1d989f6fab8f3d3a05efa0c712c7df6d1990a85865702ae76ccab67cdd72
step/assembly_frame/28_u_hip_r_mount_clearanced.step | 1922257 | b936dbd56ba705f3c0f3866b8af337783efc2fed5a09924c26c86ab03840cf1b
step/assembly_frame/29_z_bot2_master_shoulder2_2_sts3250_clearanced.step | 1862946 | bff291aed065786da3eeaedfdfad6f048c17ee5f7b19c842bb463c1de5e1f3ae
step/assembly_frame/30_z_bot2_master_shoulder2_sts3250_clearanced.step | 1911264 | d71cdae497aea627dfd4e2c354c699c332f98771a42ed7b8037ba931b5c81440
step/print_oriented/01_head_front_5mm_each_side.step | 234466 | 7ec0ba1268c11583d6667f7c2b4c13bb36e6addd87147f41dabd92c3c83c8942
step/print_oriented/02_head_rear_5mm_each_side.step | 259122 | 748030281d133fdcbac56cbc178de6afb0cafc6dfafae6f8156ace5fb5d43680
step/print_oriented/03_head_simple_visor.step | 76769 | ef4cb347a1ba43d05a9fbf187855a4280ae8e48439e1995d8b9a9530cf42ae5a
step/print_oriented/04_battery_service_cage.step | 246733 | fd10b8540d63c0e2c373ae75ed6a7f4d85f152445e161f9c9a84013aff636842
step/print_oriented/05_compute_removable_tray.step | 256635 | 40687adc24e7dad5ec5134f511fd9f49748cc6858172cb470f3a1bba21217322
step/print_oriented/06_harness_strain_relief_guides.step | 651925 | 0fc0f24aaac200ea175d7f91b2591841145c0a5858c1303b476fb67f0c53c9d9
step/print_oriented/07_torso_imu_shelf.step | 65757 | a4bd2125ee19151e12922f203f2bd231a9b74fbc8593dcaa3c71c08350d91c52
step/print_oriented/08_unitv2_removable_cradle.step | 307384 | 2df3816388849e808ffd1aeb6a90c70f0ac142a4ee0be6375a40d34ce57ccf13
step/print_oriented/09_3215_1flange_2_sts3250_clearanced.step | 1945927 | 2fab4d6a4cdeefea218ec52edd14885571c8eaf177f4ef553f2a8bc149de0d7c
step/print_oriented/10_3215_1flange_sts3250_clearanced.step | 1974370 | f52671c99c6acc90ae81319bbd191f626e32da4de0e4d7993aa16292a722014e
step/print_oriented/11_3215_bothflange_10_sts3250_clearanced.step | 4578080 | 04c7c7b9e383351194765bb201a73086bb15cc32b4c82d77f23cdd421e89563d
step/print_oriented/12_3215_bothflange_13_sts3250_clearanced.step | 1596325 | e38f711a83f924b3c19e69abe336101150523c885221c2eae4d168dd147cabd6
step/print_oriented/13_3215_bothflange_14_sts3250_clearanced.step | 1590521 | 9eaeef7ce89619ac8d2f8f6a20a67715ec8a76965ed7ecd198e03213c42f967a
step/print_oriented/14_3215_bothflange_5_sts3250_clearanced.step | 1729969 | 0744acd4ee643ba2a8b512b57d79770c89aac2e207593dc024757c4343c03327
step/print_oriented/15_3215_bothflange_6_sts3250_clearanced.step | 1673501 | 36465cdb80255acc7dfc12378d651abb718b8c3dbe24f028f3a1ffaed87cbdc7
step/print_oriented/16_3215_bothflange_9_sts3250_clearanced.step | 4321131 | 6c382f02f5f130a2cb227390b82f9f1a91a27d0ece7ac7adc68e92ab34aa3297
step/print_oriented/17_direct_head_torso_nut_plate.step | 81828 | e121c61a7137265e662d56ef5bd68ffd0fe773e69594105321120331ded9bd85
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

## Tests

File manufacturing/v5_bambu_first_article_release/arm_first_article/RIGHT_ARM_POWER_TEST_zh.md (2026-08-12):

# 右臂三关节低电流上电测试

## 安全边界

STS3250 官方参数为 6–12 V、12 V 空载约 0.28 A、12 V 堵转约 4.2 A。三只同时堵转的理论电流远超普通 USB/舵机驱动板能力。本流程只做无负载、低速、限流首件验证，不运行 RL policy，不接机器人电池，不做堵转或举重测试。

必须使用：可调 12 V 限流电源、5 A 保险丝、物理断电开关/急停、独立电源注入的 TTL 总线适配器。禁止从 USB 口给三只舵机供电。

## 装配顺序

1. 每只舵机单独连接，扭矩关闭，读取当前位置/电压/温度并确认总线通讯；最终 ID 尚未冻结时不要同时接入同 ID 舵机。
2. 把三只舵机置于机械中位 `2048`，保持扭矩关闭，再按中立 CAD 对齐输出桥和 carrier。
3. S03：舵机壳体固定在真实 torso 或刚性金属台架，输出桥固定 RA01。
4. S01：输出桥固定 RA01，舵机壳体固定 RA02。这是反装关节，壳体会随 RA02 转动。
5. S09：舵机壳体固定 RA02，输出桥固定 RA03。
6. RA04 不安装；其长通孔螺栓跨距尚未冻结，它不属于本轮动力链。
7. 输出桥的 PCD14 四颗 M3 和中心 M3×6 全部安装；螺钉长度以实测啮合为准。打印塑料桥只做配合，通电前必须更换为最终金属件。
8. 整条手臂用软吊带托住，使重力负载接近零；电缆留服务环且不跨关节剪切面。

## 分级通电

### A. 单舵机裸机

- 12 V，电源限流 `0.8 A`，只连接一只舵机。
- 先只读反馈；确认无异常后以不高于 `0.10 rad/s` 从当前位移动 `±5°`。
- 两向各 3 次，无复位、异响、反向或撞限位后再进入 B。

### B. 单关节装配

- 仍一次只连接/使能一只，电源限流 `1.2 A`。
- 手臂保持托举，先 `±5°`，再 `±15°`，最后只在 `RIGHT_ARM_TORQUE_CHAIN.csv` 的关节上下限内慢扫 5 次。
- 观察输出桥必须带动指定 carrier，舵机壳体必须留在清单指定 link；若相反，断电检查装反或控制方向，不用软件强行掩盖机械错误。

### C. 三舵机总线

- 三只接入后总电源限流 `3.0 A`，5 A 保险丝保留；每次只命令一个关节。
- 速度不高于 `0.15 rad/s`，每关节在其限制内往返 10 次。
- 同步记录目标/实际位置、输入电压、电流、温度和总线错误。

## 立即停机条件

- 无负载运动电流持续超过 1 A，或反复触发电源限流。
- 舵机复位、总线掉线、齿轮点击、输出桥相对滑动、螺钉松动。
- 绝对温度超过 45 ℃，或短时间温升超过环境温度 15 ℃。
- 位置误差超过 2° 且无法随减速消失。
- 任意 carrier 接触、线束被夹、层间开裂、孔边白化或金属嵌件转动。

停机后不要提高电流“顶过去”，先找机械卡滞、零位、镜像方向、螺钉长度和线束根因。

## 放行输出

把 `RIGHT_ARM_POWER_TEST_CHECKLIST.csv` 的 G00–G09 改为 PASS，并附：打印机型号、材料批次、喷嘴、切片配置、成品称重、孔补偿、三个舵机序列号/ID、零位、方向、空载电流、温升和视频。完成这些记录后，才把经验复制到左臂和整机。

STS3250 官方参数：[FEETECH STS3250](https://www.feetechrc.com/en/562636.html)

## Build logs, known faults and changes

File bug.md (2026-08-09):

# Zeroth-01 v5 机械基线 / RL 问题清单

最后更新：2026-08-10

适用分支：`codex/zeroth01-v5-16dof-solidworks-motion`

RL 动力学基线：`c5cb2c7eb892579c273e68f0436e6285e0782b34`

本次复测没有修改几何、质量、COM、惯量、碰撞体、关节轴、关节限位或 `1.2552512 N·m` 连续扭矩上限。模型为 `nq=23`、`nv=22`、`nu=16`、总质量 `2.745758514949 kg`；策略观测 46 维、动作 16 维，手臂和腿均由 PPO 输出。全部训练使用 RTX 4070 Laptop / JAX CUDA。

## 历史问题状态

| 编号 | 状态 | 结论 |
|---|---|---|
| BUG-RL-V5-001 actuator / qpos 顺序不一致 | CLOSED | 生成器按最终运动树显式生成并校验 16/16 映射。 |
| BUG-RL-V5-002 `symmetric_crouch` qpos 顺序错误 | CLOSED | `gait_neutral` 按 joint name 生成，限位、双脚接地和镜像门禁通过。 |
| BUG-RL-V5-003 足底 front/rear 语义反向 | CLOSED | 足底 site 已按世界坐标语义更正并自动检查。 |
| BUG-RL-V5-004 Git LFS 离线交付不完整 | CLOSED FOR GIT CLONE | README 已要求 `git lfs pull`；GitHub ZIP 仍不能视为完整离线包。 |
| BUG-RL-V5-005 官方零位把膝踝放在硬限位 | DIGITAL CLOSED / PHYSICAL HOLD | 新 `gait_neutral` 提供双向余量；实体零位、方向、硬挡仍需首件确认。 |
| BUG-RL-V5-006 canonical MJCF 哈希契约不一致 | CLOSED | MJCF 生成器强制写入 LF 字节；compile gate、RL handoff、actuator layout 与 delivery manifest 使用同一 SHA-256。 |
| BUG-RL-V5-007 STS3250 膝关节速度不足以复现当前跑步 | OPEN / P0 FOR REAL RUNNING | 见下文。 |

## BUG-RL-V5-006：canonical MJCF 哈希契约不一致（已关闭）

根因是 Windows 工作树中 MJCF 曾以 CRLF 写出，而 delivery manifest 对文本使用 LF 规范化；compile gate 和下游 JSON 当时哈希了工作树原始 CRLF 字节，导致同一 XML 出现两个摘要。

现在 MJCF 生成器通过二进制写入强制 LF，并在写出后拒绝任何 `CR` 字节；compile gate 记录 `sha256_exact_lf_bytes`，RL handoff、actuator layout 和 delivery manifest 由该值重生成。当前规范摘要为：

```text
1354289e37aabff35d3ceec91412df367e4e4e78d3d5185dcb3624cc38fba0b2
```

关闭门禁：工作树 MJCF 不含 CR；上述三个派生文件及 delivery manifest 摘要一致；`verify_v5_delivery_manifest.py` 全项通过。

## BUG-RL-V5-007：当前跑步依赖超过 STS3250 包络的快速膝伸展

### 结论

当前机械模型本身可以稳定站立、步行和产生飞行相，不支持“先减重才能训练”的判断。仿真跑步门禁已经通过，但当前跑姿不能部署到声明最大输出速度为 3 rad/s 的 STS3250。若实机必须跑步，需要机械/CAD 会话修改膝关节执行器或传动合同；若保留 STS3250，则应把一期范围冻结为步行，并重新定义较低速度、无飞行相的硬件门禁。

### 可复核证据

1. `Z4_robust_run` 在无限速位置目标模型中通过 8/8 个 4 s 回合：平均速度 `0.150424 m/s`，最慢回合 `0.139760 m/s`，单脚支撑 `0.27625`，飞行相 `0.03`，接触滑移 `0.042263 m/s`。
2. `L3_long_run` 通过 8/8 个 10 s 生存回合，平均速度 `0.155114 m/s`、飞行相 `0.038`，但左右膝 p95 速度分别为 `5.028` / `5.024 rad/s`，最大 `7.088` / `6.913 rad/s`，超过 3 rad/s 的样本占 `28.6%` / `28.8%`。
3. L3 左右膝 RMS 扭矩为 `0.932` / `0.935 N·m`，扭矩饱和比例 `39.3%` / `39.1%`；估算 RMS 电流 `0.799` / `0.801 A`。估算母线峰值电流 `7.222 A`、最低电压 `11.639 V`。当前失败项是速度，不是总质量、RMS 电流或母线压降。
4. 对 2,000 个参考步态做 4 种子 × 10 s 搜索：87 个候选满足膝 p95 ≤3 rad/s，但没有任何候选同时存在飞行相；出现飞行相的稳定候选中，最低膝 p95 仍为 `3.191 rad/s`，且速度只有 `0.071 m/s`、飞行占比 `0.001`。
5. v13 软速度约束 PPO：16 个更新、120,001 样本。全部 checkpoint 8/8 生存并保留飞行相，但速度仅约 `0.095–0.096 m/s`，膝 p95 仍约 `4.076–4.162 rad/s`，联合门禁 0/16。
6. 对原 Z4 强制目标位置每 20 ms 最多变化 0.06 rad 后，膝 p95 降至 `2.635 rad/s`，但 0/8 回合生存且飞行相为 0。
7. v14 在同一硬 3 rad/s 目标速率模型中训练 24 次更新、147,201 样本。12 个保存点的膝 p95 为 `2.713–2.823 rad/s`，但全部 0/8 生存，飞行相最高只有 `0.0025`。后期更高的“平均速度”来自倒地前前冲，不是有效跑步。

证据文件位于 `reports/rl_training/v5_16dof_20260809/`。其中硬目标速率是保守的执行器近似，不替代实测扭矩-速度曲线；但它已经证明当前跑姿对高速膝伸展存在结构性依赖。

### 必须由机械/CAD 会话做出的决定

1. 冻结需求：一期是“可步行”还是“必须有飞行相的跑步”。两者不能继续共用同一个 STS3250 合格声明。
2. 若必须跑步：膝关节输出至少覆盖当前 `5.1 rad/s` p95，并留工程余量；建议把动态输出目标设为不低于 `6 rad/s`，同时用实测扭矩-速度曲线证明所需输出扭矩，而不是引用空载转速。
3. 更换执行器或改变传动比后，必须同步更新安装 STEP、干涉/螺钉/线束空间、质量、COM、全惯量、碰撞体、URDF、MJCF 和 actuator config。增速传动会损失输出扭矩，不能只改配置数字。
4. 若必须保留 STS3250：当前 Z4/L3 均不得上机。需要从新的机械/执行器合同重新训练，并在 8 × 10 s 中同时满足生存、速度、飞行相、滑移以及每个膝关节 p95 ≤3 rad/s；若无法满足，应将产品要求降为快走而不是把快走命名为跑步。
5. 采购至少一个真实 STS3250，测量输出端扭矩-速度-电流、死区、背隙、延迟、热阻/热时间常数和母线内阻；完成实体零位、方向、ID、硬挡和线束全行程标定。
6. 完成原生 SolidWorks Motion 和实体首件门禁。当前 digital baseline 为 PASS，但 native motion 和 physical first article 仍为 HOLD。

### 机械修改后的回归门禁

- `nq=23`、`nv=22`、`nu=16` 与 46→16 策略合同不变，或显式版本升级；
- 60 s 中立姿态无 NaN、穿地和动力学爆炸；
- N/M/Z checkpoint 均能恢复；
- 跑步 8 × 10 s 全部存活，平均速度 ≥0.15 m/s，最慢回合 ≥0.10 m/s，单脚支撑 ≥0.15，飞行相 ≥0.02，接触滑移 ≤0.05 m/s；
- 每个关节 p95 速度和扭矩-速度工作点位于实测连续包络内；
- RMS 电流、温升、母线压降和足底冲击通过实测参数复算。

没有执行任何实体舵机命令。

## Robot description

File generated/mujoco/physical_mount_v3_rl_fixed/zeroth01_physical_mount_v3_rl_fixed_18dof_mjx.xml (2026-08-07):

<?xml version='1.0' encoding='utf-8'?>
<mujoco model="zeroth01_physical_mount_v3_rl_fixed_18dof_mjx">
  <compiler angle="radian" coordinate="local" autolimits="true" />
  <option timestep="0.002" gravity="0 0 -9.81" integrator="implicitfast" />
  <size njmax="2000" nconmax="400" />
  <default>
    <joint damping="0.035" armature="0.002" frictionloss="0.01" />
    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
  </default>
  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
  <worldbody>
    <light pos="0 -1 1.2" dir="0 0 -1" directional="true" />
    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
    <body name="Z_BOT2_MASTER_BODY_SKELETON" pos="0 0 0" quat="0.707388269167 0 0 0.706825181105">
      <freejoint name="floating_base" />
      <inertial pos="0 0 -0.025" mass="0.743471828" diaginertia="0.00240472129038 0.00269126736067 0.00108124077985" />
      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
      <body name="Z_BOT2_MASTER_SHOULDER2" pos="0.055995 -0.01061 -0.009528" quat="1.22474523098e-07 1.22474483074e-07 0.707106665647 0.707106896726">
        <joint name="left_shoulder_yaw" type="hinge" axis="0 0 1" range="-0.12 0.12" limited="true" />
        <inertial pos="-0.0104225 -0.00245 0.0094" mass="0.02" diaginertia="3.98041666667e-06 5.83389004167e-06 4.26550670833e-06" />
        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
        <body name="3215_1Flange" pos="-0.020845 -0.0049 0.0188" quat="0.500000163397 -0.5 0.499999836603 -0.5">
          <joint name="left_shoulder_pitch" type="hinge" axis="0 0 1" range="-0.47123889 0.47123889" limited="true" />
          <inertial pos="0.046492 0.0099 -0.0093" mass="0.149" diaginertia="6.51080333333e-05 0.000225751889845 0.000227277649845" />
          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
          <body name="R_ARM_MIRROR_1" pos="0.092984 0.0198 -0.0186" quat="-1.22474523098e-07 -1.22474483074e-07 0.707106665647 0.707106896726">
            <joint name="left_elbow_yaw" type="hinge" axis="0 0 -1" range="-0.34 0.24" limited="true" />
            <inertial pos="-0.033103 -0.005889 0.00063" mass="0.03" diaginertia="6.09609221e-06 2.432729509e-05 2.61426493e-05" />
            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
            <body name="FINGER_1" pos="-0.066206 -0.011778 0.00126" quat="-9.93463784844e-08 0.573576508925 0.819151993472 -1.41881305656e-07">
              <inertial pos="0 0 0" mass="0.025" diaginertia="5.4e-06 5.4e-06 5.4e-06" />
              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
            </body>
          </body>
        </body>
      </body>
      <body name="Z_BOT2_MASTER_SHOULDER2_2" pos="-0.055995 -0.01061 -0.009528" quat="0.707106896726 -0.707106665647 0 0">
        <joint name="right_shoulder_yaw" type="hinge" axis="0 0 1" range="-0.12 0.12" limited="true" />
        <inertial pos="-0.0104225 0.00245 0.0094" mass="0.02" diaginertia="3.98041666667e-06 5.83389004167e-06 4.26550670833e-06" />
        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
        <body name="3215_1Flange_2" pos="-0.020845 0.0049 0.0188" quat="0.500000163397 0.5 0.499999836603 0.5">
          <joint name="right_shoulder_pitch" type="hinge" axis="0 0 1" range="-0.47123889 0.47123889" limited="true" />
          <inertial pos="0.046492 -0.0099 -0.0093" mass="0.149" diaginertia="6.51080333333e-05 0.000225751889845 0.000227277649845" />
          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
          <body name="L_ARM_MIRROR_1" pos="0.092984 -0.0198 -0.0186" quat="0.500000163397 -0.5 -0.5 -0.499999836603">
            <joint name="right_elbow_yaw" type="hinge" axis="0 0 1" range="-0.24 0.34" limited="true" />
            <inertial pos="-0.005889 0.033103 -0.00063" mass="0.03" diaginertia="2.432729509e-05 6.09609221e-06 2.61426493e-05" />
            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
            <body name="FINGER_1_2" pos="-0.011778 0.066206 -0.00126" quat="0.984807740023 3.29132692615e-21 -8.69526751844e-21 0.173648251331">
              <inertial pos="0 0 0" mass="0.025" diaginertia="5.4e-06 5.4e-06 5.4e-06" />
              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
            </body>
          </body>
        </body>
      </body>
      <body name="U_HIP_L" pos="0.042808 0.007735 -0.083418" quat="3.00000078125e-14 -1.7320510331e-07 1 -1.7320510331e-07">
        <joint name="left_hip_yaw" type="hinge" axis="0 0 1" range="-0.322013241 0.026179939" limited="true" />
        <inertial pos="3.46944695195e-18 0.00885 0.0282" mass="0.02" diaginertia="1.367175e-05 1.17336e-05 3.85815e-06" />
        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
        <body name="3215_BothFlange_5" pos="0 0.0177 0.0564" quat="0.707106896726 -0.707106665647 0 0">
          <joint name="left_hip_roll" type="hinge" axis="0 0 -1" range="-0.06 0.22" limited="true" />
          <inertial pos="-0.0032 -0.016 -0.00895" mass="0.0995" diaginertia="5.08976495833e-05 3.00106095833e-05 4.28592933333e-05" />
          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
          <body name="3215_BothFlange_9" pos="-0.0064 -0.032 -0.0179" quat="0.500000163397 0.5 -0.499999836603 -0.5">
            <joint name="left_hip_pitch" type="hinge" axis="0 0 1" range="-0.027495556 0.412327408" limited="true" />
            <inertial pos="0.05 0.005 -0.00063" mass="0.1745" diaginertia="5.09584730167e-05 0.000289150973017 0.000299732833333" />
            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
            <body name="3215_BothFlange_13" pos="0.1 0.01 -0.00126" quat="1 0 0 0">
              <joint name="left_knee_pitch" type="hinge" axis="0 0 1" range="-0.83285928 0" limited="true" />
              <inertial pos="0.05 0 0.0004" mass="0.229" diaginertia="4.51710133333e-05 0.000365771013333 0.000364720666667" />
              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
              <body name="left_ankle_roll_carrier" pos="0.1 0 0.0008" quat="1.22474523098e-07 0.707106896726 0.707106665647 1.22474483074e-07">
                <joint name="left_ankle_pitch" type="hinge" axis="0 0 1" range="-0.66415928 0" limited="true" />
                <inertial pos="1.49999983927e-08 0.015 2.94226351616e-10" mass="0.0995" diaginertia="3.43938336066e-05 1.30013475366e-05 3.43938472633e-05" />
                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
                <body name="FOOT" pos="2.99999967854e-08 0.03 5.88452703232e-10" quat="1 0 0 0">
                  <joint name="left_ankle_roll" type="hinge" axis="-0.999999683467 1.00001518318e-06 -0.000795653505717" range="-0.25 0.25" limited="true" />
                  <inertial pos="0.0100000183347 0.0214999899998 7.95695678161e-06" mass="0.07" diaginertia="3.31749480895e-05 0.000103549005693 7.09457424679e-05" />
                  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
                </body>
              </body>
            </body>
          </body>
        </body>
      </body>
      <body name="U_HIP_R" pos="-0.042868 0.007735 -0.083418" quat="3.00000078125e-14 -1.7320510331e-07 1 -1.7320510331e-07">
        <joint name="right_hip_yaw" type="hinge" axis="0 0 1" range="-0.026179939 0.322013241" limited="true" />
        <inertial pos="0 -0.00885 0.0282" mass="0.02" diaginertia="1.367175e-05 1.17336e-05 3.85815e-06" />
        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
        <body name="3215_BothFlange_6" pos="0 -0.0177 0.0564" quat="1.22474523098e-07 -1.22474483074e-07 -0.707106665647 0.707106896726">
          <joint name="right_hip_roll" type="hinge" axis="0 0 1" range="-0.22 0.06" limited="true" />
          <inertial pos="-0.0032 -0.016 -0.00945" mass="0.0995" diaginertia="5.17002829167e-05 3.08132429167e-05 4.28592933333e-05" />
          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
          <body name="3215_BothFlange_10" pos="-0.0064 -0.032 -0.0189" quat="0.500000163397 0.5 -0.499999836603 -0.5">
            <joint name="right_hip_pitch" type="hinge" axis="0 0 1" range="-0.412327408 0.027495556" limited="true" />
            <inertial pos="0.05 -0.005 -0.00063" mass="0.1745" diaginertia="5.09584730167e-05 0.000289150973017 0.000299732833333" />
            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
            <body name="3215_BothFlange_14" pos="0.1 -0.01 -0.00126" quat="1 0 0 0">
              <joint name="right_knee_pitch" type="hinge" axis="0 0 1" range="0 0.83285928" limited="true" />
              <inertial pos="0.05 0 0.0005" mass="0.229" diaginertia="4.54374166667e-05 0.000366037416667 0.000364720666667" />
              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
              <body name="right_ankle_roll_carrier" pos="0.1 0 0.001" quat="1.22474523098e-07 0.707106896726 -0.707106665647 -1.22474483074e-07">
                <joint name="right_ankle_pitch" type="hinge" axis="0 0 1" range="0 0.66415928" limited="true" />
                <inertial pos="5.19615470096e-09 -0.015 -1.00980746508e-08" mass="0.0995" diaginertia="3.43938427111e-05 1.30013475366e-05 3.43938381588e-05" />
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

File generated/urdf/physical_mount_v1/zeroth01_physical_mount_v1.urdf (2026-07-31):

<?xml version='1.0' encoding='utf-8'?>
<robot name="zeroth01_physical_mount_v1_sts3250_16dof">
  <link name="floating_base_link">
    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
    <inertial name="floating_base_link_inertial">
      <mass value="0.001" />
      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
      <origin xyz="0 0 0" rpy="0.00 0.00 1.57" />
    </inertial>
  </link>
  <joint name="floating_base_joint" type="fixed">
    <parent link="floating_base_link" />
    <child link="Z_BOT2_MASTER_BODY_SKELETON" />
    <origin xyz="0 0 0" rpy="0.00 0.00 1.57" />
  </joint>
  <joint name="imu" type="fixed">
    <origin xyz="0.044470 0.006575 -0.025518" rpy="1.570796 0 -1.570796" />
    <parent link="Z_BOT2_MASTER_BODY_SKELETON" />
    <child link="IMU_2" />
  </joint>
  <joint name="left_shoulder_yaw" type="revolute">
    <origin xyz="0.055995 -0.010610 -0.009528" rpy="1.570796 0 -3.141593" />
    <parent link="Z_BOT2_MASTER_BODY_SKELETON" />
    <child link="Z_BOT2_MASTER_SHOULDER2" />
    <limit effort="1.569" velocity="3.0" lower="-0.120000000" upper="0.120000000" />
    <axis xyz="0 0 1" />
    <dynamics damping="0.05" friction="0.02" />
  </joint>
  <joint name="right_shoulder_yaw" type="revolute">
    <origin xyz="-0.055995 -0.010610 -0.009528" rpy="-1.570796 0 0" />
    <parent link="Z_BOT2_MASTER_BODY_SKELETON" />
    <child link="Z_BOT2_MASTER_SHOULDER2_2" />
    <limit effort="1.569" velocity="3.0" lower="-0.120000000" upper="0.120000000" />
    <axis xyz="0 0 1" />
    <dynamics damping="0.05" friction="0.02" />
  </joint>
  <joint name="left_hip_yaw" type="revolute">
    <origin xyz="0.042808 0.007735 -0.083418" rpy="3.141593 0 3.141593" />
    <parent link="Z_BOT2_MASTER_BODY_SKELETON" />
    <child link="U_HIP_L" />
    <limit effort="1.569" velocity="3.0" lower="-0.322013241" upper="0.026179939" />
    <axis xyz="0 0 1" />
    <dynamics damping="0.05" friction="0.02" />
  </joint>
  <joint name="right_hip_yaw" type="revolute">
    <origin xyz="-0.042868 0.007735 -0.083418" rpy="3.141593 0 3.141593" />
    <parent link="Z_BOT2_MASTER_BODY_SKELETON" />
    <child link="U_HIP_R" />
    <limit effort="1.569" velocity="3.0" lower="-0.026179939" upper="0.322013241" />
    <axis xyz="0 0 1" />
    <dynamics damping="0.05" friction="0.02" />
  </joint>
  <joint name="left_shoulder_pitch" type="revolute">
    <origin xyz="-0.020845 -0.004900 0.018800" rpy="-1.570796 0 -1.570796" />
    <parent link="Z_BOT2_MASTER_SHOULDER2" />
    <child link="3215_1Flange" />
    <limit effort="1.569" velocity="3.0" lower="-0.471238890" upper="0.471238890" />
    <axis xyz="0 0 1" />
    <dynamics damping="0.05" friction="0.02" />
  </joint>
  <joint name="right_shoulder_pitch" type="revolute">
    <origin xyz="-0.020845 0.004900 0.018800" rpy="1.570796 0 1.570796" />
    <parent link="Z_BOT2_MASTER_SHOULDER2_2" />
    <child link="3215_1Flange_2" />
    <limit effort="1.569" velocity="3.0" lower="-0.471238890" upper="0.471238890" />
    <axis xyz="0 0 1" />
    <dynamics damping="0.05" friction="0.02" />
  </joint>
  <joint name="left_hip_roll" type="revolute">
    <origin xyz="0 0.017700 0.056400" rpy="-1.570796 0 0" />
    <parent link="U_HIP_L" />
    <child link="3215_BothFlange_5" />
    <limit effort="1.569" velocity="3.0" lower="-0.060000000" upper="0.220000000" />
    <axis xyz="0 0 -1.0" />
    <dynamics damping="0.05" friction="0.02" />
  </joint>
  <joint name="right_hip_roll" type="revolute">
    <origin xyz="0 -0.017700 0.056400" rpy="-1.570796 0 -3.141593" />
    <parent link="U_HIP_R" />
    <child link="3215_BothFlange_6" />
    <limit effort="1.569" velocity="3.0" lower="-0.220000000" upper="0.060000000" />
    <axis xyz="0 0 1" />
    <dynamics damping="0.05" friction="0.02" />
  </joint>
  <joint name="left_hip_pitch" type="revolute">
    <origin xyz="-0.006400 -0.032000 -0.017900" rpy="1.570796 0 -1.570796" />
    <parent link="3215_BothFlange_5" />
    <child link="3215_BothFlange_9" />
    <limit effort="1.569" velocity="3.0" lower="-0.027495556" upper="0.412327408" />
    <axis xyz="0 0 1" />
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

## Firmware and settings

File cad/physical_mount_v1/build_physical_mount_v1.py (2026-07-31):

from __future__ import annotations

import argparse
import csv
import hashlib
import json
import math
import shutil
import xml.etree.ElementTree as ET
from collections import defaultdict
from pathlib import Path

from PIL import Image
from vtkmodules.vtkCommonMath import vtkMatrix4x4
from vtkmodules.vtkFiltersCore import (
    vtkAppendPolyData,
    vtkCleanPolyData,
    vtkPolyDataConnectivityFilter,
)
from vtkmodules.vtkIOGeometry import vtkSTLReader, vtkSTLWriter
from vtkmodules.vtkIOImage import vtkPNGWriter
from vtkmodules.vtkRenderingCore import (
    vtkActor,
    vtkPolyDataMapper,
    vtkRenderWindow,
    vtkRenderer,
    vtkWindowToImageFilter,
)

# Register the OpenGL backend when VTK is installed as split vtkmodules.
import vtkmodules.vtkRenderingOpenGL2  # noqa: F401


ROOT = Path(__file__).resolve().parents[2]
CONFIG_PATH = ROOT / "config" / "physical_mount_v1_source_regions.json"
CAD_ROOT = ROOT / "generated" / "cad" / "physical_mount_v1"
SKELETON_DIR = CAD_ROOT / "skeleton"
SERVO_DIR = CAD_ROOT / "servos"
URDF_ROOT = ROOT / "generated" / "urdf" / "physical_mount_v1"
URDF_SKELETON_DIR = URDF_ROOT / "meshes" / "skeleton"
URDF_SERVO_DIR = URDF_ROOT / "meshes" / "servos"
URDF_PATH = URDF_ROOT / "zeroth01_physical_mount_v1.urdf"
ACTUATOR_PATH = (
    ROOT / "generated" / "config" / "physical_mount_v1_actuators.json"
)
REPORT_ROOT = ROOT / "reports" / "physical_mount_v1"
MANIFEST_PATH = REPORT_ROOT / "servo_component_manifest.json"
MANIFEST_CSV = REPORT_ROOT / "servo_component_manifest.csv"
GATE_PATH = REPORT_ROOT / "source_component_gate.json"
INERTIA_REPORT = REPORT_ROOT / "sts3250_inertia_delta.json"
SNAPSHOT_ROOT = ROOT / "snapshots" / "physical_mount_v1"
MOTION_ROOT = SNAPSHOT_ROOT / "motion_frames"
FRONT_SNAPSHOT = SNAPSHOT_ROOT / "physical_mount_v1_16_blue_servos_front.png"
XRAY_SNAPSHOT = SNAPSHOT_ROOT / "physical_mount_v1_16_blue_servos_xray.png"
MOTION_GIF = SNAPSHOT_ROOT / "physical_mount_v1_16dof_motion.gif"
GUARDED_LIMITS = ROOT / "reports" / "joint_servo_frames.csv"
PHYSICAL_GUARDED_LIMITS = (
    ROOT / "config" / "physical_mount_v1_guarded_limits.json"
)

STS3215_MASS_KG = 0.055
STS3250_MASS_KG = 0.0745
STS3250_MASS_TOLERANCE_KG = 0.001
SERVO_DELTA_MASS_KG = STS3250_MASS_KG - STS3215_MASS_KG
IDENTITY_R = (
    (1.0, 0.0, 0.0),
    (0.0, 1.0, 0.0),
    (0.0, 0.0, 1.0),
)


def _parse_vec(
    text: str | None,
    default: tuple[float, float, float] = (0.0, 0.0, 0.0),
) -> tuple[float, float, float]:
    if not text:
        return default
    values = tuple(float(value) for value in text.split())
    if len(values) != 3:
        raise ValueError(text)
    return values


def _mat_mul(
    first: tuple[tuple[float, ...], ...],
    second: tuple[tuple[float, ...], ...],
) -> tuple[tuple[float, ...], ...]:
    return tuple(
        tuple(
            sum(first[row][index] * second[index][column] for index in range(3))
            for column in range(3)
        )
        for row in range(3)
    )


def _mat_vec(
    matrix: tuple[tuple[float, ...], ...],
    vector: tuple[float, float, float],
) -> tuple[float, float, float]:
    return tuple(
        sum(matrix[row][column] * vector[column] for column in range(3))
        for row in range(3)
    )


def _vec_add(
    first: tuple[float, float, float],
    second: tuple[float, float, float],
) -> tuple[float, float, float]:
    return tuple(first[index] + second[index] for index in range(3))


def _tf_mul(
    first: tuple[tuple[tuple[float, ...], ...], tuple[float, ...]],
    second: tuple[tuple[tuple[float, ...], ...], tuple[float, ...]],
) -> tuple[tuple[tuple[float, ...], ...], tuple[float, ...]]:
    first_r, first_t = first
    second_r, second_t = second
    return _mat_mul(first_r, second_r), _vec_add(
        _mat_vec(first_r, second_t), first_t
    )


def _rpy_matrix(
    rpy: tuple[float, float, float],
) -> tuple[tuple[float, ...], ...]:
    roll, pitch, yaw = rpy
    cr, sr = math.cos(roll), math.sin(roll)
    cp, sp = math.cos(pitch), math.sin(pitch)
    cy, sy = math.cos(yaw), math.sin(yaw)
    rx = ((1.0, 0.0, 0.0), (0.0, cr, -sr), (0.0, sr, cr))
    ry = ((cp, 0.0, sp), (0.0, 1.0, 0.0), (-sp, 0.0, cp))
    rz = ((cy, -sy, 0.0), (sy, cy, 0.0), (0.0, 0.0, 1.0))
    return _mat_mul(rz, _mat_mul(ry, rx))


def _axis_angle_matrix(
    axis: tuple[float, float, float],
    angle: float,
) -> tuple[tuple[float, ...], ...]:
    norm = math.sqrt(sum(value * value for value in axis))
    if norm <= 1e-12:
        return IDENTITY_R
    x_pos, y_pos, z_pos = (value / norm for value in axis)
    cosine = math.cos(angle)
    sine = math.sin(angle)
    remainder = 1.0 - cosine
    return (
        (
            cosine + x_pos * x_pos * remainder,
            x_pos * y_pos * remainder - z_pos * sine,
            x_pos * z_pos * remainder + y_pos * sine,
        ),
        (
            y_pos * x_pos * remainder + z_pos * sine,
            cosine + y_pos * y_pos * remainder,
            y_pos * z_pos * remainder - x_pos * sine,
        ),
        (
            z_pos * x_pos * remainder - y_pos * sine,
            z_pos * y_pos * remainder + x_pos * sine,
            cosine + z_pos * z_pos * remainder,
        ),
    )


def _sha256(path: Path) -> str:
    digest = hashlib.sha256()
    with path.open("rb") as stream:
        for block in iter(lambda: stream.read(1024 * 1024), b""):
            digest.update(block)
    return digest.hexdigest()


def _read_clean_mesh(path: Path) -> object:
    reader = vtkSTLReader()
    reader.SetFileName(str(path))
    reader.Update()
    clean = vtkCleanPolyData()
    clean.SetInputConnection(reader.GetOutputPort())
    clean.Update()
    return clean.GetOutput()


def _connectivity(polydata: object) -> object:
    connection = vtkPolyDataConnectivityFilter()
    connection.SetInputData(polydata)
    connection.SetExtractionModeToAllRegions()
    connection.ColorRegionsOn()
    connection.Update()
    return connection


def _extract_region(polydata: object, region_id: int) -> object:
    extract = vtkPolyDataConnectivityFilter()
    extract.SetInputData(polydata)
    extract.SetExtractionModeToSpecifiedRegions()
    extract.AddSpecifiedRegion(region_id)
    extract.Update()
    clean = vtkCleanPolyData()
    clean.SetInputConnection(extract.GetOutputPort())
    clean.Update()
    return clean.GetOutput()


def _append_regions(polydata: object, region_ids: list[int]) -> object:
    append = vtkAppendPolyData()
    for region_id in region_ids:
        append.AddInputData(_extract_region(polydata, region_id))
    append.Update()
    clean = vtkCleanPolyData()
    clean.SetInputConnection(append.GetOutputPort())
    clean.Update()
    return clean.GetOutput()


def _write_stl(polydata: object, path: Path) -> None:
    path.parent.mkdir(parents=True, exist_ok=True)
    writer = vtkSTLWriter()
    writer.SetFileName(str(path))
    writer.SetFileTypeToBinary()
    writer.SetInputData(polydata)
    if writer.Write() != 1:
        raise RuntimeError(f"failed to write {path}")


def _used_bounds(polydata: object) -> tuple[float, ...]:
    point_ids: set[int] = set()
    for cell_id in range(polydata.GetNumberOfCells()):
        ids = polydata.GetCell(cell_id).GetPointIds()
        for index in range(ids.GetNumberOfIds()):
            point_ids.add(int(ids.GetId(index)))
    points = [polydata.GetPoint(point_id) for point_id in point_ids]
    if not points:
        raise ValueError("empty polydata region")
    return (
        min(point[0] for point in points),
        max(point[0] for point in points),
        min(point[1] for point in points),
        max(point[1] for point in points),
        min(point[2] for point in points),
        max(point[2] for point in points),
    )


def _bounds_size(bounds: tuple[float, ...]) -> tuple[float, float, float]:
    return (
        bounds[1] - bounds[0],
        bounds[3] - bounds[2],
        bounds[5] - bounds[4],
    )


def _bounds_center(bounds: tuple[float, ...]) -> tuple[float, float, float]:
    return (
        (bounds[0] + bounds[1]) / 2.0,
        (bounds[2] + bounds[3]) / 2.0,
        (bounds[4] + bounds[5]) / 2.0,
    )


def _load_guarded_limits() -> dict[str, tuple[float, float]]:
    limits: dict[str, tuple[float, float]] = {}
    with GUARDED_LIMITS.open(encoding="utf-8-sig", newline="") as stream:
        for row in csv.DictReader(stream):
            limits[str(row["joint"])] = (
                float(row["guarded_lower_rad"]),
                float(row["guarded_upper_rad"]),
            )
    overrides = json.loads(
        PHYSICAL_GUARDED_LIMITS.read_text(encoding="utf-8")
    )["limits"]
    for joint, values in overrides.items():
        limits[str(joint)] = (float(values[0]), float(values[1]))
    return limits


def _source_link_meshes(
    root: ET.Element,
) -> dict[str, str]:
    result: dict[str, str] = {}
    for link in root.findall("link"):
        mesh = link.find("./visual/geometry/mesh")
        if mesh is None:
            continue
        filename = str(mesh.get("filename", ""))
        if not filename:
            continue
        result[str(link.get("name"))] = Path(filename).name
    return result


def split_source_geometry(
    config: dict[str, object],
    source_mesh_root: Path,
    link_meshes: dict[str, str],
) -> tuple[list[dict[str, object]], dict[str, str], dict[str, list[dict[str, object]]]]:
    servos = list(config["servos"])
    by_mesh: dict[str, list[dict[str, object]]] = defaultdict(list)
    for servo in servos:
        by_mesh[str(servo["source_mesh"])].append(servo)

    manifest: list[dict[str, object]] = []
    skeleton_meshes: dict[str, str] = {}
    servos_by_link: dict[str, list[dict[str, object]]] = defaultdict(list)
    processed_files: dict[str, Path] = {}

    for link_name, mesh_name in link_meshes.items():
        source = source_mesh_root / mesh_name
        if not source.is_file():
            raise FileNotFoundError(source)
        target = SKELETON_DIR / mesh_name
        mapped = by_mesh.get(mesh_name, [])
        if not mapped:
            target.parent.mkdir(parents=True, exist_ok=True)
            shutil.copy2(source, target)
            skeleton_meshes[link_name] = mesh_name
            processed_files[mesh_name] = target
            continue

        polydata = _read_clean_mesh(source)
        connection = _connectivity(polydata)
        region_count = int(connection.GetNumberOfExtractedRegions())
        mapped_ids = {int(item["region_id"]) for item in mapped}
        if not mapped_ids.issubset(set(range(region_count))):
            raise ValueError(
                f"{mesh_name} regions {sorted(mapped_ids)} outside 0..{region_count - 1}"
            )
        remaining_ids = [
            region_id
            for region_id in range(region_count)
            if region_id not in mapped_ids
        ]
        if not remaining_ids:
            raise ValueError(f"{mesh_name} has no carrier geometry after split")
        _write_stl(_append_regions(polydata, remaining_ids), target)
        skeleton_meshes[link_name] = mesh_name
        processed_files[mesh_name] = target

        for servo in mapped:
            region_id = int(servo["region_id"])
            servo_polydata = _extract_region(polydata, region_id)
            bounds = _used_bounds(servo_polydata)
            size_mm = tuple(value * 1000.0 for value in _bounds_size(bounds))
            center_m = _bounds_center(bounds)
            sorted_size = sorted(size_mm)
            family_fit = (
                abs(sorted_size[2] - 45.22) <= 1.0
                and abs(sorted_size[1] - 37.4) <= 1.0
                and 24.0 <= sorted_size[0] <= 28.5
            )
            filename = (
                f"{servo['id']}_{servo['joint']}_"
                "INSTALLED_STS3215_FAMILY.stl"
            )
            servo_path = SERVO_DIR / filename
            _write_stl(servo_polydata, servo_path)
            entry = {
                **servo,
                "output_mesh": str(servo_path.relative_to(ROOT)).replace("\\", "/"),
                "source_region_triangles": int(
                    servo_polydata.GetNumberOfCells()
                ),
                "source_region_points": int(
                    servo_polydata.GetNumberOfPoints()
                ),
                "bounds_m": [round(value, 9) for value in bounds],
                "center_m_in_owning_link": [
                    round(value, 9) for value in center_m
                ],
                "size_mm": [round(value, 6) for value in size_mm],
                "family_envelope_gate": "PASS" if family_fit else "FAIL",
                "source_sha256": _sha256(source),
                "output_sha256": _sha256(servo_path),
                "mounting_semantics": (
                    "EXTRACTED_IN_PLACE_FROM_ORIGINAL_ASSEMBLED_ZEROTH_LINK; "
                    "NO_TRANSLATION_OR_HOUSING_PHASE_ADDED"
                ),
            }
            manifest.append(entry)
            servos_by_link[str(servo["owning_link"])].append(entry)

    if len(manifest) != 16:
        raise ValueError(f"expected 16 servos, got {len(manifest)}")
    manifest.sort(key=lambda row: str(row["id"]))
    return manifest, skeleton_meshes, servos_by_link


def _write_manifest(manifest: list[dict[str, object]]) -> None:
    MANIFEST_PATH.parent.mkdir(parents=True, exist_ok=True)
    MANIFEST_PATH.write_text(
        json.dumps(
            {
                "schema": "zeroth01.physical_mount_v1.servo_manifest.v1",
                "servo_count": len(manifest),
                "servos": manifest,
            },
            indent=2,
            ensure_ascii=False,
        )
        + "\n",
        encoding="utf-8",
    )
    fields: list[str] = []
    for row in manifest:
        for key in row:
            if key not in fields:
                fields.append(key)
    with MANIFEST_CSV.open("w", encoding="utf-8-sig", newline="") as stream:
        writer = csv.DictWriter(
            stream,
            fieldnames=fields,
            extrasaction="ignore",
        )
        writer.writeheader()
        writer.writerows(manifest)


def _parallel_axis(
    mass: float,
    offset: tuple[float, float, float],
) -> list[list[float]]:
    x_pos, y_pos, z_pos = offset
    return [
        [mass * (y_pos * y_pos + z_pos * z_pos), -mass * x_pos * y_pos, -mass * x_pos * z_pos],
        [-mass * x_pos * y_pos, mass * (x_pos * x_pos + z_pos * z_pos), -mass * y_pos * z_pos],
        [-mass * x_pos * z_pos, -mass * y_pos * z_pos, mass * (x_pos * x_pos + y_pos * y_pos)],
    ]


def _add_matrix(first: list[list[float]], second: list[list[float]]) -> list[list[float]]:
    return [
        [first[row][column] + second[row][column] for column in range(3)]
        for row in range(3)
    ]


def update_inertias(
    root: ET.Element,
    servos_by_link: dict[str, list[dict[str, object]]],
) -> list[dict[str, object]]:
    report: list[dict[str, object]] = []
    for link in root.findall("link"):
        link_name = str(link.get("name"))
        additions = servos_by_link.get(link_name, [])
        if not additions:
            continue
        inertial = link.find("inertial")
        if inertial is None:
            raise ValueError(f"{link_name} has no inertial")
        mass_element = inertial.find("mass")
        inertia_element = inertial.find("inertia")
        origin_element = inertial.find("origin")
        if mass_element is None or inertia_element is None:
            raise ValueError(f"{link_name} inertial is incomplete")
        old_mass = float(mass_element.get("value", "0"))
        old_center = _parse_vec(
            origin_element.get("xyz") if origin_element is not None else None
        )
        old_inertia = [
            [
                float(inertia_element.get("ixx", "0")),
                float(inertia_element.get("ixy", "0")),
                float(inertia_element.get("ixz", "0")),
            ],
            [
                float(inertia_element.get("ixy", "0")),
                float(inertia_element.get("iyy", "0")),
                float(inertia_element.get("iyz", "0")),
            ],
            [
                float(inertia_element.get("ixz", "0")),
                float(inertia_element.get("iyz", "0")),
                float(inertia_element.get("izz", "0")),
            ],
        ]
        new_mass = old_mass + SERVO_DELTA_MASS_KG * len(additions)
        weighted = [
            old_mass * old_center[index]
            + SERVO_DELTA_MASS_KG
            * sum(
                float(item["center_m_in_owning_link"][index])
                for item in additions
            )
            for index in range(3)
        ]
        new_center = tuple(value / new_mass for value in weighted)
        old_offset = tuple(
            old_center[index] - new_center[index] for index in range(3)
        )
        new_inertia = _add_matrix(
            old_inertia,
            _parallel_axis(old_mass, old_offset),
        )
        for addition in additions:
            center = tuple(
                float(value) for value in addition["center_m_in_owning_link"]
            )
            offset = tuple(
                center[index] - new_center[index] for index in range(3)
            )
            new_inertia = _add_matrix(
                new_inertia,
                _parallel_axis(SERVO_DELTA_MASS_KG, offset),
            )

        mass_element.set("value", f"{new_mass:.9f}")
        if origin_element is None:
            origin_element = ET.SubElement(inertial, "origin")
        origin_element.set(
            "xyz", " ".join(f"{value:.9f}" for value in new_center)
        )
        origin_element.set("rpy", "0 0 0")
        inertia_element.attrib.update(
            {
                "ixx": f"{new_inertia[0][0]:.12g}",
                "iyy": f"{new_inertia[1][1]:.12g}",
                "izz": f"{new_inertia[2][2]:.12g}",
                "ixy": f"{new_inertia[0][1]:.12g}",
                "ixz": f"{new_inertia[0][2]:.12g}",
                "iyz": f"{new_inertia[1][2]:.12g}",
            }
        )
        report.append(
            {
                "link": link_name,
                "servo_ids": [item["id"] for item in additions],
                "old_mass_kg": old_mass,
                "new_mass_kg": new_mass,
                "old_com_m": list(old_center),
                "new_com_m": list(new_center),
                "method": (
                    "replace archived 55 g STS3215-family actuator mass with "
                    "74.5 g STS3250 by a 19.5 g point-mass delta at each "
                    "extracted actuator-region centre"
                ),
            }
        )
    INERTIA_REPORT.write_text(
        json.dumps(
            {
                "schema": "zeroth01.physical_mount_v1.inertia_delta.v1",
                "source_servo_mass_kg": STS3215_MASS_KG,
                "target_servo_mass_kg": STS3250_MASS_KG,
                "delta_per_servo_kg": SERVO_DELTA_MASS_KG,
                "links": report,
            },
            indent=2,
        )
        + "\n",
        encoding="utf-8",
    )
    return report
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

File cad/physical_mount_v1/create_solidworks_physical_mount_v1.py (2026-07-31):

from __future__ import annotations

import argparse
import csv
import gc
import importlib.util
import json
import math
import subprocess
import sys
import time
import traceback
from collections import defaultdict
from pathlib import Path

import pythoncom
import win32com.client as win32
import win32com.client.dynamic as win32_dynamic
from PIL import Image


ROOT = Path(__file__).resolve().parents[2]
BASE_SCRIPT = ROOT / "scripts" / "create_solidworks_kinematic_review.py"
BUILD_SCRIPT = Path(__file__).with_name("build_physical_mount_v1.py")
CAD_SITE_PACKAGES = (
    ROOT.parents[1] / ".venv-cad" / "Lib" / "site-packages"
)
if str(CAD_SITE_PACKAGES) not in sys.path:
    sys.path.insert(0, str(CAD_SITE_PACKAGES))


def _load_module(name: str, path: Path):
    spec = importlib.util.spec_from_file_location(name, path)
    if spec is None or spec.loader is None:
        raise RuntimeError(f"cannot import {path}")
    module = importlib.util.module_from_spec(spec)
    spec.loader.exec_module(module)
    return module


base = _load_module("zeroth01_sw_kinematic_base", BASE_SCRIPT)
physical = _load_module("zeroth01_physical_mount_build", BUILD_SCRIPT)

URDF_PATH = physical.URDF_PATH
MANIFEST_PATH = physical.MANIFEST_PATH
SKELETON_DIR = physical.SKELETON_DIR
SERVO_DIR = physical.SERVO_DIR
STEP_SOURCE_ROOT = (
    ROOT / "generated" / "cad" / "physical_mount_v1" / "step"
)
SW_ROOT = ROOT / "generated" / "solidworks" / "physical_mount_v1"
PART_ROOT = SW_ROOT / "parts"
SKELETON_PART_ROOT = PART_ROOT / "skeleton"
SERVO_PART_ROOT = PART_ROOT / "servos"
LINK_ASM_ROOT = SW_ROOT / "links"
TOP_ASM = SW_ROOT / "OPEN_FIRST_ZEROTH01_PHYSICAL_MOUNT_V1_16_BLUE_SERVOS.SLDASM"
XRAY_ASM = SW_ROOT / "ZEROTH01_PHYSICAL_MOUNT_V1_16_BLUE_SERVOS_XRAY.SLDASM"
SNAPSHOT_ROOT = ROOT / "snapshots" / "solidworks" / "physical_mount_v1"
FRAME_ROOT = SNAPSHOT_ROOT / "motion_frames"
MOTION_GIF = SNAPSHOT_ROOT / "solidworks_physical_mount_v1_16dof_motion.gif"
REPORT_ROOT = ROOT / "reports" / "physical_mount_v1"
TRACE_LOG = REPORT_ROOT / "solidworks_physical_mount_trace.log"
PART_REPORT = REPORT_ROOT / "solidworks_physical_mount_parts.csv"
LINK_REPORT = REPORT_ROOT / "solidworks_physical_mount_link_subassemblies.csv"
COMPONENT_REPORT = REPORT_ROOT / "solidworks_physical_mount_components.csv"
GATE_REPORT = REPORT_ROOT / "solidworks_physical_mount_gate.json"

SW_DOC_PART = 1
SW_DOC_ASSEMBLY = 2
SW_OPEN_SILENT = 1
SW_SAVE_AS_CURRENT_VERSION = 0
SW_SAVE_AS_SILENT = 1
SW_IMPORT_STL_VRML_MODEL_TYPE = 208
SW_IMPORT_STL_VRML_UNITS = 210
SW_IMPORT_AS_SURFACE = 1
SW_LENGTH_UNIT_METER = 2
SW_EXE = Path(r"E:\SolidWorks\SOLIDWORKS\SLDWORKS.exe")
SW_WARMUP_PART = (
    SKELETON_PART_ROOT
    / "ZEROTH01_PHYSICAL_MOUNT_V1_3215_1FLANGE_CARRIER.SLDPRT"
)
WHITE = (0.93, 0.95, 0.98)
BLUE = (0.086, 0.467, 1.0)


def trace(message: str) -> None:
    REPORT_ROOT.mkdir(parents=True, exist_ok=True)
    stamp = time.strftime("%Y-%m-%d %H:%M:%S")
    with TRACE_LOG.open("a", encoding="utf-8") as stream:
        stream.write(f"{stamp} {message}\n")
    print(message, flush=True)


def typed_sldworks(sw):
    module = win32.gencache.EnsureModule(
        base.SW_MAIN_TYPELIB,
        0,
        33,
        0,
    )
    return module.ISldWorks(sw._oleobj_)


def iter_sw_apps():
    """Yield SolidWorks sessions registered in the Running Object Table.

    GetActiveObject/Dispatch can block indefinitely while SolidWorks is
    starting. Enumerating the ROT keeps startup observable and lets this
    script enforce its own timeout.
    """
    rot = pythoncom.GetRunningObjectTable()
    enum = rot.EnumRunning()
    context = pythoncom.CreateBindCtx(0)
    while True:
        monikers = enum.Next(1)
        if not monikers:
            break
        moniker = monikers[0]
        try:
            name = moniker.GetDisplayName(context, None)
        except Exception:
            continue
        if not name.startswith("SolidWorks_PID_"):
            continue
        try:
            # Force a no-type-info wrapper.  Once the SolidWorks makepy
            # modules are loaded, both Dispatch and GetActiveObject select
            # an early-bound wrapper whose ActiveDoc is null for a
            # just-opened STL in SW 2025.  DumbDispatch preserves the ROT
            # object's working late-bound behavior.
            obj = pythoncom.GetActiveObject("SldWorks.Application")
            app = win32_dynamic.DumbDispatch(
                obj.QueryInterface(pythoncom.IID_IDispatch),
                userName=name,
            )
        except Exception:
            continue
        yield name, app


def get_or_start_sw(
    timeout_s: float = 240.0,
    startup_file: Path | None = None,
):
    apps = list(iter_sw_apps())
    if apps:
        trace(f"SolidWorks ROT attach: {apps[0][0]}")
        sw = apps[0][1]
        sw.Visible = True
        sw.CommandInProgress = False
        return sw

    if not SW_EXE.is_file():
        raise FileNotFoundError(SW_EXE)
    trace(f"SolidWorks launch requested: {SW_EXE}")
    launch_command = [str(SW_EXE)]
    selected_startup_file = (
        startup_file
        if startup_file is not None and startup_file.is_file()
        else SW_WARMUP_PART
    )
    if selected_startup_file.is_file():
        launch_command.append(str(selected_startup_file))
    process = subprocess.Popen(
        launch_command,
        stdin=subprocess.DEVNULL,
        stdout=subprocess.DEVNULL,
        stderr=subprocess.DEVNULL,
        close_fds=True,
        creationflags=subprocess.CREATE_NEW_PROCESS_GROUP,
    )
    trace(f"SolidWorks spawned pid={process.pid}")
    deadline = time.monotonic() + timeout_s
    next_status = time.monotonic() + 5.0
    while time.monotonic() < deadline:
        apps = list(iter_sw_apps())
        if apps:
            trace(
                f"SolidWorks ROT ready: {apps[0][0]} "
                f"after_pid={process.pid}"
            )
            sw = apps[0][1]
            sw.Visible = True
            sw.CommandInProgress = False
            return sw
        return_code = process.poll()
        if return_code is not None:
            raise RuntimeError(
                "SolidWorks exited before COM registration: "
                f"pid={process.pid} code={return_code}"
            )
        if time.monotonic() >= next_status:
            trace(
                "SolidWorks startup pending: "
                f"pid={process.pid} elapsed_s="
                f"{timeout_s - (deadline - time.monotonic()):.1f}"
            )
            next_status = time.monotonic() + 5.0
        time.sleep(0.5)

    trace(
        f"SolidWorks startup timeout: pid={process.pid} "
        f"timeout_s={timeout_s:.1f}"
    )
    process.terminate()
    try:
        process.wait(timeout=8.0)
    except subprocess.TimeoutExpired:
        process.kill()
        process.wait(timeout=8.0)
    raise TimeoutError(
        f"SolidWorks did not register COM within {timeout_s:.1f}s"
    )
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

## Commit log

2026-07-29 Publish Zeroth-01 round-v1 RL mechanical package
    [Left_Hand.stl, Torso.stl, ZEROTH01_LINK_FOOT_LEFT.SLDPRT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]
2026-07-30 Integrate servo load path and RL sensor package
    [ZEROTH01_ROUND_V1_BATTERY_PACK.SLDPRT, ZEROTH01_ROUND_V1_BATTERY_PACK.step, ZEROTH01_ROUND_V1_CAMERA_LENSES.SLDPRT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]
2026-07-30 Publish minimal-cosmetic Zeroth-01 RL mechanical baseline
    [ZEROTH01_LINK_FOOT_LEFT.SLDPRT, ZEROTH01_LINK_FOOT_RIGHT.SLDPRT, ZEROTH01_LINK_HIP_ROLL_LEFT.SLDPRT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]
2026-07-30 Publish Round V3 ears rounded arms and chibi hands
    [ZEROTH01_LINK_FOOT_LEFT.SLDPRT, ZEROTH01_LINK_FOOT_RIGHT.SLDPRT, ZEROTH01_LINK_HIP_ROLL_LEFT.SLDPRT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]
2026-07-31 replace diagnostic overlays with physical mount v1
    [3215_1Flange.collision.stl, 3215_1Flange.stl, 3215_1Flange_2.collision.stl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]
2026-07-31 release physical mount v2 minimal
    [3215_1Flange.stl, 3215_1Flange_2.stl, 3215_BothFlange_10.stl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]
2026-08-06 release: add SolidWorks v3 RL-fixed 18DoF baseline
    [3215_1Flange.stl, 3215_1Flange_2.stl, 3215_BothFlange_10.stl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]
2026-08-07 Release v3 RL-fixed CoreS3 mechanical package
    [PROCUREMENT_BOM.csv, ZEROTH01_V3_CORES3_INTERNAL_TORSO_CRADLE_2MM_6061.SLDPRT, ZEROTH01_V3_LEFT_ANKLE_ROLL_CARRIER.SLDPRT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]
2026-08-07 release Zeroth-01 v4 original-minimal 18DoF baseline
    [3215_1Flange.stl, 3215_1Flange_2.stl, 3215_BothFlange_10.stl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]
2026-08-08 Fix Zeroth-01 actuator load paths and remove redundant parts
    [PROCUREMENT_BOM.csv, V4_REUSED_ZEROTH01_V3_LEFT_SOLE_LIGHTWEIGHTED.SLDPRT, V4_REUSED_ZEROTH01_V3_RIGHT_SOLE_LIGHTWEIGHTED.SLDPRT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]
2026-08-08 Add Zeroth-01 v5 original 16DoF RL mechanical baseline
    [3215_1Flange.stl, 3215_1Flange_2.stl, 3215_1Flange_2_STS3250_CLEARANCED.step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]
2026-08-09 Fix v5 RL model contract and reset pose
    [zeroth01_physical_mount_v5_original_16dof_solidworks_motion_mjx.xml]
2026-08-09 Add walking and running RL checkpoints with STS3250 audit
    [L3_foot_impact_slip_statistics.csv, L3_joint_hardware_statistics.csv, M4_joint_hardware_statistics.csv]
2026-08-09 feat: freeze v5 Bambu first-article print release
    [01_head_front_5mm_each_side.3mf, 01_head_front_5mm_each_side.step, 01_head_front_5mm_each_side.stl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]
2026-08-12 feat: add right-arm first-article print kit
    [FC01_01_sts3250_4xm2_first_article_face_gauge.3mf, FC01_01_sts3250_4xm2_first_article_face_gauge.step, FC02_02_sts3250_parent_thrust_ring_2mm.3mf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]
